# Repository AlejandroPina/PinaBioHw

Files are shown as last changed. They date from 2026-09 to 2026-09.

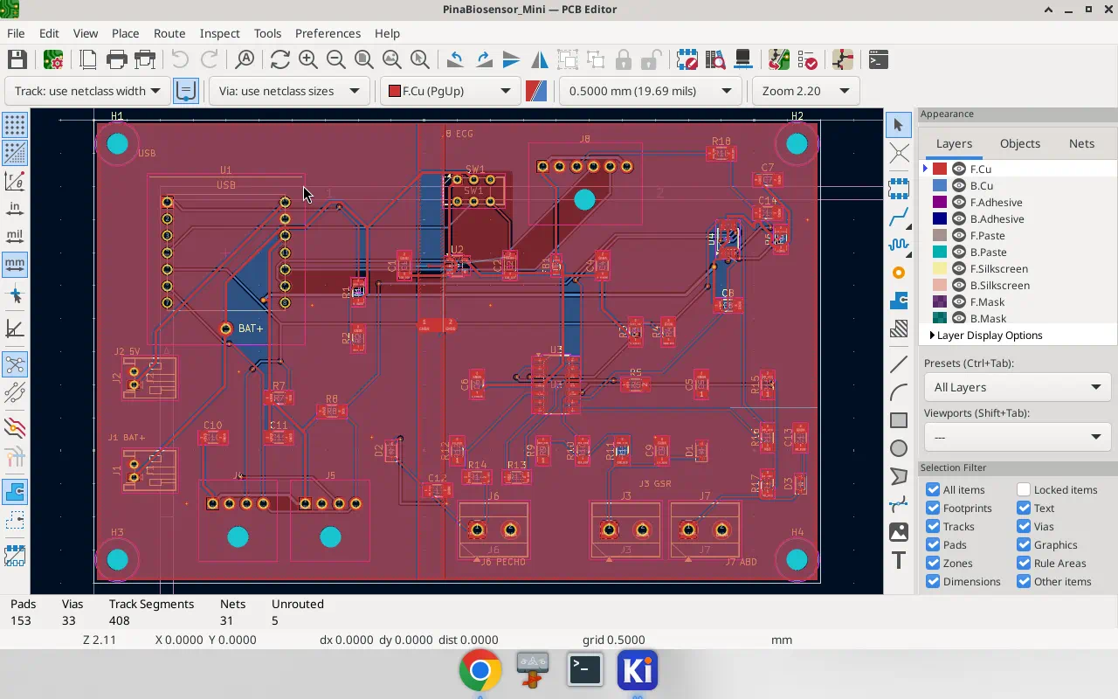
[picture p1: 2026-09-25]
exports/kicad_open.png

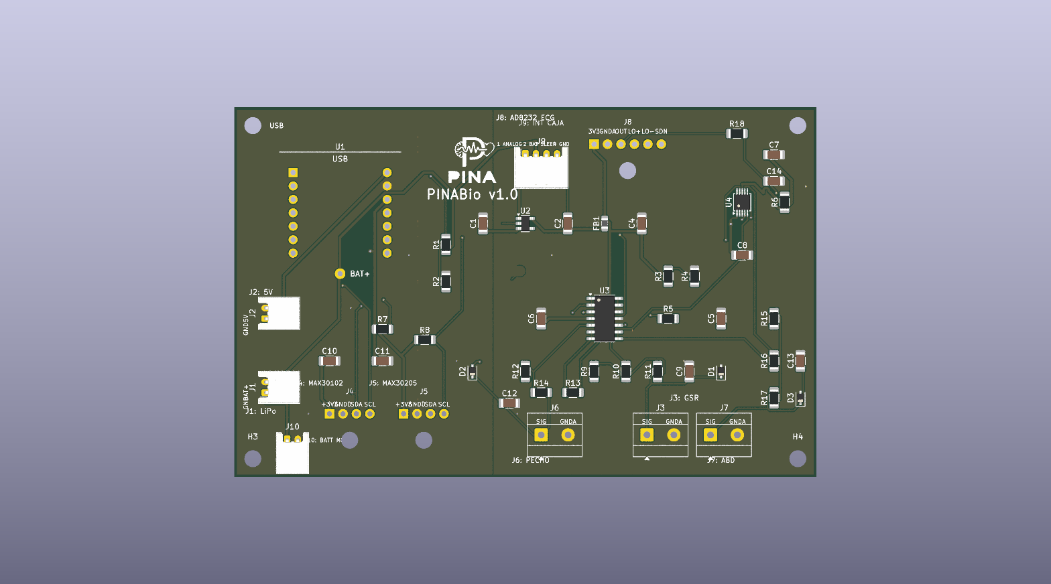
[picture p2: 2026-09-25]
exports/pcb_3d_caja.png

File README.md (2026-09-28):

[English](#) | [Español](README.es.md)

**Versión en español:** [README.es.md](README.es.md)

# PinaBio v1.0 (Paca)

The **paid JLCPCB order** is **v1.0** (`exports/PinaBio_v1_*`). A **v1.1 layout** (XIAO USB at the board edge) is ready for a **later** spin: `exports/PinaBio_v1.1_*` and `docs/10_pinabio_v1.1_rf.md`. Same circuit. Do not mix v1.1 files into the current order.

**PinaBio** is a **biofeedback** board (skin conductance, pulse, temperature, ECG, breathing). It is **not a medical device** and does not diagnose anything. The nickname **Paca** is a tribute to Alejandro’s grandmother.

Phone Bluetooth advertises as **`PinaBiosensor`**. Keep this BLE name for firmware clients.

## What the board is

One PCB, about **110 × 70 mm**, microcontroller **Seeed XIAO ESP32-S3** in a socket:

- GSR (skin)
- Pulse / HRV (MAX30102) — raw PPG for external HRV analysis
- Temperature (MAX30205)
- ECG (AD8232 module — lab toy, not a hospital ECG)
- Chest + abdomen breathing (stretch bands that change resistance)

Older notes call this same board “Completa”. KiCad files stay named `PinaBiosensor_Mini.*` on purpose (renaming breaks the project). Silk says **PINA** / **PINABio v1.0** (no “Paca” on copper — it does not fit).

Charge the XIAO from its USB-C. **With electrodes or bands on skin: Bluetooth only. Never USB from a PC and skin at the same time.**

The paid v1.0 fabrication trio is in `exports/` on `main`: `PinaBio_v1_gerbers.zip`, `PinaBio_v1_bom_jlc.csv` and `PinaBio_v1_cpl.csv`. Their committed bytes match `exports/archive_v1.0/SHA256SUMS`. See the [order guide](docs/08_jlcpcb_order.md) before a repeat order.

## Safety (read this)

This design is **not** USB-isolated. Full text: `docs/04_seguridad.md`.

1. **Never** USB to a computer while GSR, bands, or ECG electrodes are on the body.
2. Charge / flash firmware with **skin disconnected**.
3. A session with skin = **BLE only**.
4. LiPo **with a protection board** only. JST J1: pin 1 +, pin 2 ground.
5. Not for diagnosis, not for use on wounds, not a medical product.

## Order PCBs (JLCPCB)

**5** bare boards, **2** assembled (PCBA). Step-by-step: [English order guide](docs/08_jlcpcb_order.md) · [Español](docs/08_pedido_jlcpcb.md).

For a repeat order, use the three `PinaBio_v1_*` files in `exports/` on `main` and verify their hashes against `exports/archive_v1.0/SHA256SUMS`. The old `kicad-completa` branch is no longer needed. Do **not** substitute the loose `exports/gerbers/` files or the v1.1 package.

## Firmware

Board sketch (Arduino, XIAO ESP32-S3):

`firmware/PinaBiosensor_Firmware_v1_3/PinaBiosensor_Firmware_v1_3.ino`

Firmware 1.2 is kept at `firmware/PinaBiosensor_Firmware_v1_2/` for rollback.

BLE name: `PinaBiosensor`. Current protocol: `docs/firmware_v1_3_protocol.en.md` (binary byte still `0x12`, same as 1.2). Instructions: `firmware/README.md`. Changes: `firmware/CHANGELOG_v1_3.md`.

Firmware debug JSON is v4. Binary frame details are in the protocol specification.

## Open the PCB in KiCad

See `docs/03_guia_kicad.md`. Short version:

1. Install [KiCad 8](https://www.kicad.org/) **with libraries**. Do not create a new project.
2. Open `hardware/PinaBiosensor_Mini.kicad_pro`.
3. The schematic is a text map. The board you order is the PCB.

## Suggested fab (summary)

- JLCPCB / PCBWay, 2 layers, FR4 1.6 mm, green mask, HASL or ENIG.
- Factory SMT: 1206, SOT-23-5, SOIC-14, ADS1115 (VSSOP-10, very small).
- You fit: XIAO, MAX/AD8232 modules, battery, box switch on **J9**, optional meter on **J10**.

Design BOM: `bom/BOM.csv`.

## More docs

- `docs/02_arquitectura.md` — architecture
- `docs/04_seguridad.md` — safety (EN + ES)
- `docs/firmware_v1_3_protocol.en.md` — BLE UUIDs and current frames (byte `0x12`)
- `docs/firmware_v1_2_protocol.en.md` — V1.2 frames (kept for rollback)
- `docs/08_jlcpcb_order.md` — order (English)
- `docs/08_pedido_jlcpcb.md` — pedido (español)
- `docs/09_caja_interruptor_medidor.md` — box DPDT (4 wires) and J10

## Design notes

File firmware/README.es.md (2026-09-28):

# Firmware PinaBiosensor 1.3 — Paca v1.0 fabricada

[English](README.md) · [Protocolo 1.3](../docs/firmware_v1_3_protocol.es.md) · [Guía 1.3](../docs/firmware_v1_3_code_guide.es.md) · [Verificación](../docs/firmware_v1_3_verification.md) · [Cambios 1.3](CHANGELOG_v1_3.md)

**Sketch vigente:** `PinaBiosensor_Firmware_v1_3/PinaBiosensor_Firmware_v1_3.ino`

**Se conserva por si hay que volver:** `PinaBiosensor_Firmware_v1_2/` con [protocolo 1.2](../docs/firmware_v1_2_protocol.es.md) y [changelog 1.2](CHANGELOG_v1_2.md).

Mismo hardware Paca v1.0, nombre BLE `PinaBiosensor`, Wi-Fi apagado. No es dispositivo médico. Los frames binarios siguen con byte **`0x12`**.

## Compilación y carga

Arduino IDE o CLI, placa **Seeed XIAO ESP32-S3**, core Arduino-ESP32 y SparkFun MAX3010x. Carpeta y `.ino` con el mismo nombre. Electrodes fuera antes de USB.

## Uso

Los mismos comandos que 1.2. `STATUS` empieza por `fw=1.3 proto=0x12`. `STOP` pone a cero la vista previa de pulso. `START` sigue pudiendo devolver `ERR START_PPG_FIFO`.

No hay interlock por software de USB (no hay GPIO de VBUS). Cargar con power bank está bien; piel fuera mientras el cable esté puesto.

## Verificación

1.3 corrige comportamiento de 1.2. Hay que compilar y medir SPS de ECG en la XIAO tras el cambio del sondeo ADS.

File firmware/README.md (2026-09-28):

# Firmware PinaBiosensor 1.3 — fabricated Paca v1.0

[Español](README.es.md) · [Protocol 1.3](../docs/firmware_v1_3_protocol.en.md) · [Code guide 1.3](../docs/firmware_v1_3_code_guide.en.md) · [Verification](../docs/firmware_v1_3_verification.md) · [Changelog 1.3](CHANGELOG_v1_3.md)

**Current sketch:** `PinaBiosensor_Firmware_v1_3/PinaBiosensor_Firmware_v1_3.ino`

**Kept for rollback:** `PinaBiosensor_Firmware_v1_2/` with [protocol 1.2](../docs/firmware_v1_2_protocol.en.md) and [changelog 1.2](CHANGELOG_v1_2.md).

Same Paca v1.0 hardware: ADS1115 `0x49`, MAX30102 `0x57`, MAX30205 `0x48`; D4/D5 I²C, D3/GPIO4 sleep, D8/D9 leads-off, D0/A0 battery. BLE name `PinaBiosensor`. Wi-Fi off. Not a medical device. Binary frames still use version byte **`0x12`**.

## Build and upload

Arduino IDE or Arduino CLI, board **Seeed XIAO ESP32-S3**, Arduino-ESP32 core, SparkFun MAX3010x Pulse and Proximity Sensor Library. Folder name must match the `.ino`. Disconnect electrodes before USB flash.

## Operation

Same commands as 1.2 (`START`, `STOP`, `STATUS`, `USB_MODE`, rates, `SLEEP`, …). `STATUS` starts with `fw=1.3 proto=0x12`. `STOP` clears the on-MCU pulse preview. `START` still returns `ERR START_PPG_FIFO` if the MAX30102 FIFO cannot be verified.

There is no software USB-presence interlock (no VBUS GPIO). Charge with a power bank if you want; still keep skin contacts off while the cable is in.

## Verification status

1.3 is a behavioural fix on 1.2. Compile and bring-up on the XIAO are required before calling it session-ready. Measure ECG SPS after the ADS poll change.

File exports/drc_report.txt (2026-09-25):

** Drc report for PinaBiosensor_Mini.kicad_pcb **
** Created on 2026-09-12T10:42:11+0000 **

** Found 0 DRC violations **

** Found 0 unconnected pads **

** Found 0 Footprint errors **

** End of Report **

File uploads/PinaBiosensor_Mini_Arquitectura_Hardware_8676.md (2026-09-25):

# Documento de Arquitectura de Hardware: PinaBiosensor Mini

**Versión:** 1.0 (basada en PinaBiosensor 1.0 v2.0, reducida)
**Objetivo:** Especificaciones para el diseño de la PCB en KiCad de una versión simplificada del biofeedback, centrada en tres señales: **conductancia de la piel (GSR)**, **temperatura de la piel** y **pletismografía/HRV (PPG)**.

Este documento asume que llevas tiempo sin tocar electrónica, así que cada bloque incluye un breve repaso de "por qué" antes del "cómo".

---

## 0. Qué cambia respecto a la versión completa

| Bloque | Versión completa | Versión Mini |
|---|---|---|
| ECG (AD8232) | Sí | **Eliminado** |
| Respiración (bandas resistivas x2) | Sí | **Eliminado** |
| GSR | Sí (jack TRRS) | Sí, pero con **terminal de tornillo** |
| SpO2/PPG (MAX30102) | Sí (jack TRRS) | Sí, **cable soldado directo** |
| Temperatura | Analógica, vía ADS1115 (no existía en la versión completa; aquí se introduce) | **MAX30205, digital I2C**, cable soldado directo |
| MCP6004 (op-amp) | 3 canales en uso (A, B, C) | **1 canal en uso (A)**, resto sin usar (ver §3.4) |
| ADS1115 | 4 canales multiplexados | **1 canal en uso (AIN1)** |
| Conectores de sensores | AudioJack4 (TRRS 3.5mm) | Terminal de tornillo (GSR) + pads soldados con anclaje (I2C) |
| Alimentación, carga, switch ON/OFF | — | **Sin cambios** |

---

## 1. Microcontrolador

**Seeed Studio XIAO ESP32-S3**, montado igual que en la versión completa: no va soldado directamente a la placa base, sino insertado en dos tiras de conectores hembra `Conn_01x07`, para poder sacarlo y reprogramarlo o reutilizarlo en otro proyecto.

---

## 2. Sistema de Alimentación (sin cambios)

Repaso rápido de por qué esto es así, ya que es la parte más delicada del diseño:

- **V_BATT**: la batería LiPo se conecta directamente al pin `BAT` del XIAO. El propio módulo XIAO ya incluye el circuito de carga (chip cargador de Li-Po), así que no hay que diseñar nada de carga desde cero.
- **Monitor de batería**: un divisor resistivo de dos resistencias de 47kΩ (1%) reduce la tensión de la batería a la mitad, y ese punto medio va al pin `A0` (ADC interno del ESP32-S3) para poder leer el nivel de batería por software.
- **V_ANALOG (3.3V "limpios")**: la circuitería analógica (sensores) es sensible al ruido que meten los circuitos digitales (el WiFi/BLE del XIAO, por ejemplo). Por eso no se alimenta directamente de V_BATT, sino de un regulador LDO dedicado (**ADP150AUJZ-3.3**), seguido de un filtro LC (ferrita de 600Ω @ 100MHz + condensador de 10µF) que actúa como un "colador" de ruido de alta frecuencia.
- **V_REF (0.5V exactos)**: tensión de referencia necesaria para el circuito de GSR (ver §3.1). Se genera con un divisor de precisión (56kΩ y 10kΩ al 0.1%) desde V_ANALOG, y se "bufferiza" con un amplificador operacional en configuración seguidor de tensión — es decir, el op-amp copia esa tensión pero con muy baja impedancia de salida, para que no varíe cuando el circuito de GSR "tire" de corriente de ella.

**Interruptor ON/OFF (SW1)** y **carga (J_CHARGE, J_BATT)**: idénticos a la versión completa. El interruptor solo corta la alimentación del dominio analógico (V_ANALOG) y fuerza el microcontrolador a Deep Sleep (contacto a GPIO3), pero **nunca interrumpe la ruta de carga**, que va directa a los pads BAT del XIAO. Esto significa que puedes cargar la batería con el sistema "apagado" sin ningún problema — no hay que rediseñar nada aquí.

---

## 3. Sensores

### 3.1 Conductancia de la Piel (GSR) — el sensor más delicado

**Repaso del concepto:** la piel actúa como una resistencia variable que cambia con la sudoración (respuesta de conductancia, muy usada en biofeedback de estrés/relajación). Para medirla, hacemos un divisor de tensión donde una de las "resistencias" es la propia piel, y medimos el punto medio.

**Topología** (idéntica a la versión completa):

```
V_REF (0.5V) → R_FIXED (100kΩ) → Nodo_MID → Electrodos (piel) → GNDA
```

- El **Nodo_MID** se conecta a `AIN1` del ADS1115.
- **Electrodos**: par de electrodos Velcro tipo GSR/SC (los que te han recomendado), conectados a la placa mediante un **terminal de tornillo de 2 pines** (ver §4). No es necesario respetar polaridad — la piel actúa como resistencia pura, no como diodo.

**Filtros de protección** (mantener tal cual, incluso más importantes ahora sin jack blindado):

1. **C_shunt (100nF)**: en paralelo con los electrodos, entre el terminal de tornillo y GNDA. Estabiliza la lectura frente a pequeños movimientos/contactos intermitentes.
2. **R_limit (470Ω)**: en serie entre el Nodo_MID y el pin AIN1, protege la entrada del ADC.
3. **R_series (47Ω)**: en serie justo a la entrada del terminal de tornillo, protección ESD (descargas electrostáticas) — recuerda que aquí hay piel humana en contacto directo con el circuito.

**ADC**: el ADS1115 se alimenta desde V_ANALOG, con `ADDR` conectado también a V_ANALOG (fija la dirección I2C en `0x49`). Ya que solo usamos un canal, el firmware configura ganancia ×8 (rango ±0.512V) para aprovechar toda la resolución del ADC en el rango de tensión donde se mueve la señal.

### 3.2 Pletismografía / HRV — MAX30102

Sensor óptico todo-en-uno (LED + fotodiodo + ADC interno), dirección I2C `0x57`. No necesita ningún acondicionamiento analógico externo — toda la "electrónica difícil" ya está dentro del chip.

- **VCC** → V_ANALOG (alimentación limpia; mejora la relación señal/ruido de la medida óptica).
- **GND** → GNDD (es un chip digital con picos de corriente al encender los LEDs; conviene que esos picos vayan al plano digital y no contaminen GNDA).
- **SDA/SCL** → bus I2C compartido (pull-ups de 2.2kΩ a 3.3V digital, ya presentes en el bus).
- **Conexión física**: cable de 4 hilos soldado directo a 4 pads en la placa (ver §4).

### 3.3 Temperatura de la Piel — MAX30205 (recomendado sobre NTC)

Sensor digital I2C específico para temperatura corporal, dirección `0x48`.

**Por qué este y no un NTC** (repaso, ya que llevas tiempo sin ver esto): un NTC es una resistencia que cambia con la temperatura, pero para leerla necesitas (a) un divisor de tensión con otra resistencia de precisión, (b) un canal ADC libre, y (c) calcular la temperatura con una fórmula de calibración (ecuación de Steinhart-Hart) en el firmware. El MAX30205 se salta los tres pasos: es un termómetro que habla I2C y te devuelve grados directamente, con una resolución de 0.0039°C — más que suficiente para detectar las tendencias lentas típicas del biofeedback de temperatura periférica (técnica de "manos calientes").

- **VCC** → V_ANALOG
- **GND** → GNDD
- **SDA/SCL** → mismo bus I2C
- **Conexión física**: cable de 4 hilos soldado directo (comparte el mismo patrón de pads que el MAX30102, ver §4).

### 3.4 Amplificador Operacional MCP6004 — uso reducido

En la versión completa se usaban 3 de los 4 canales del MCP6004 (buffer de V_REF, y dos buffers de respiración). En la versión Mini **solo se usa el canal A** (buffer de V_REF para el GSR).

**Importante (repaso de un detalle que se olvida fácilmente):** los canales B, C y D del MCP6004 **no pueden quedar con la entrada al aire**. Un op-amp con la entrada flotante puede oscilar y meter ruido de alta frecuencia en toda la placa, incluyendo en el canal A que sí usas (todos comparten el mismo chip y la misma alimentación interna). La solución estándar y sin coste: conecta la entrada no inversora de cada canal no usado a GNDA, y realimenta la salida a la entrada inversora (configuración de seguidor de tensión con entrada a masa). Esto los deja "en reposo" de forma segura.

---

## 4. Conectores de Sensores (nuevo respecto a la versión completa)

Se elimina el conector `AudioJack4` (TRRS) para todos los sensores. En su lugar:

| Sensor | Conector | Motivo |
|---|---|---|
| GSR (electrodos Velcro) | **Terminal de tornillo, 2 pines**, paso 5.08mm | Se pone y se quita en cada uso; no requiere soldar ni crimpar, solo pelar el hilo e insertarlo |
| MAX30102 | **4 pads pasantes** (VCC, GND, SDA, SCL) + 1 **agujero de anclaje** junto a ellos | Cable soldado directo, se instala una vez; el agujero permite pasar una brida o poner pegamento caliente para evitar que el tirón del cable arranque los pads |
| MAX30205 | **4 pads pasantes** (VCC, GND, SDA, SCL) + 1 **agujero de anclaje** | Igual que el anterior |

**Recomendación práctica de montaje:** separa los pads lo suficiente (al menos 2.54mm entre centros) para poder soldar cómodamente con un soldador normal, y coloca el agujero de anclaje a unos 5mm del grupo de pads, no pegado a ellos, para que la brida no interfiera con la soldadura.

---

## 5. Planos de Masa (sin cambios de criterio, menos superficie a repartir)

- **GNDA** (masa analógica): bajo el ADS1115, el MCP6004, y el circuito de GSR (R_FIXED, C_shunt, terminal de tornillo).
- **GNDD** (masa digital): bajo el XIAO, el bus I2C, y los pads de MAX30102/MAX30205.
- **Net-Tie**: un único punto de unión entre GNDA y GNDD, situado cerca del LDO ADP150 y del XIAO, igual que en la versión completa.

Al haber menos componentes analógicos, el plano GNDA es más pequeño, pero el criterio de separación es exactamente el mismo: evitar que el ruido digital (conmutación del XIAO, BLE) se cuele en la medida de GSR, que es la más sensible de las tres señales.

---

## 6. Clases de Red (Net Classes)

Sin cambios respecto a la versión completa:

- **Alimentación** (V_BATT, 3.3V, V_ANALOG): 0.4–0.5 mm de ancho de pista.
- **Señales analógicas** (Nodo_MID del GSR, V_REF): 0.25 mm, alejadas de las pistas I2C.
- **Bus I2C** (SDA, SCL): 0.25 mm, cortas y paralelas, sobre el plano GNDD.

---

## 7. Lista de Componentes (BOM) — resumen

| Componente | Cantidad | Notas |
|---|---|---|
| Seeed XIAO ESP32-S3 | 1 | Módulo plug-in, no soldado |
| Conn_01x07 hembra | 2 | Zócalo para el XIAO |
| LDO ADP150AUJZ-3.3 | 1 | V_ANALOG |
| Ferrita 600Ω @ 100MHz | 1 | Filtro LC de V_ANALOG |
| Condensador 10µF | 1 | Filtro LC de V_ANALOG |
| Resistencias 47kΩ 1% | 2 | Divisor monitor de batería |
| Resistencias 56kΩ / 10kΩ 0.1% | 1 + 1 | Divisor V_REF |
| MCP6004 | 1 | Solo canal A en uso |
| Condensador 4.7µF | 1 | Estabilidad salida buffer V_REF |
| ADS1115 | 1 | Solo canal AIN1 en uso |
| Resistencias pull-up I2C 2.2kΩ | 2 | SDA, SCL |
| Resistencia R_FIXED 100kΩ | 1 | Divisor GSR |
| Condensador C_shunt 100nF | 1 | GSR |
| Resistencia R_limit 470Ω | 1 | GSR |
| Resistencia R_series 47Ω | 1 | GSR |
| Terminal de tornillo 2 pines, 5.08mm | 1 | Electrodos GSR |
| MAX30102 (módulo/breakout) | 1 | I2C 0x57, pads soldados |
| MAX30205 | 1 | I2C 0x48, pads soldados |
| SW1 (interruptor doble contacto) | 1 | Sin cambios vs. versión completa |
| J_CHARGE, J_BATT | 1 + 1 | Sin cambios |

---

## Siguiente documento

Como no tienes experiencia previa con KiCad, el siguiente documento (`PinaBiosensor_Mini_Guia_KiCad_Principiantes.md`) te lleva paso a paso desde instalar el programa hasta generar los ficheros para fabricar esta placa concreta.

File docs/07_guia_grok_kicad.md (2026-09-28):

# Encargo para Grok — generar KiCad de PinaBio v1.0

Documento para pegar o adjuntar a **Grok** (Cursor u otro agente con acceso al repo y a KiCad).  
Autor del proyecto: Alejandro. **No es un dispositivo médico.**

---

## 0. ¿Es posible?

**Sí, con matices.**

| Encargo | Realista |
|---|---|
| Esquemático **de verdad** (símbolos + hilos + etiquetas globales) | Sí, si Grok usa KiCad 8 y las librerías de este repo |
| PCB colocada, planos GNDA/GNDD, net-tie | Sí |
| Pistas **sin errores DRC** (listo para JLCPCB) | **A veces no a la primera.** Debe **iterar**: DRC → corregir → DRC hasta 0 errores. No entregar Manhattan sucio y decir “listo” |
| Firmware | El sketch V1.2 está en `firmware/`; esta guía se centra en KiCad, Gerbers y BOM |

Si no tienes KiCad instalado, **no inventes un `.kicad_pcb` a mano**. Di que falta KiCad. No sustituyas la placa por un dibujo ASCII.

---

## 1. Qué eres y qué no

Eres el **layoutista**. El circuito **ya está decidido**. No “mejoras” la arquitectura (no cambies pines de sleep, no pongas cargador extra, no alimentes I2C desde V_ANALOG, no uses GPIO3 para el interruptor).

**Olvida la Mini como producto.** El diseño se llama **PinaBio v1.0**. Los archivos KiCad siguen `PinaBiosensor_Mini.*` (**no los renombres**). El ZIP original del pedido está restaurado como `exports/PinaBio_v1_gerbers.zip` en `main`; su hash coincide con `exports/archive_v1.0/SHA256SUMS`. No lo sustituyas por los gerbers sueltos de `exports/gerbers/`.

---

## 2. Archivos que debes leer primero (en este orden)

1. Este archivo: `docs/07_guia_grok_kicad.md`
2. `docs/02_arquitectura.md`
3. `docs/04_seguridad.md`
4. `scripts/generate_kicad.py` — **fuente eléctrica** (nets y pines)
5. `hardware/sym-lib/Pina.kicad_sym`
6. `hardware/footprints.pretty/` (XIAO zócalo, cables 4P y 6P)
7. `firmware/PinaBiosensor_Firmware_v1_3/PinaBiosensor_Firmware_v1_3.ino` — firmware vigente y pines de la PCB v1.0 (no contradecir). V1.2 se conserva para rollback.

No uses `uploads/PinaBiosensor_Mini_Guia_KiCad_Principiantes_*.md` (está mal: GPIO3, etiquetas jerárquicas, sensores a V_ANALOG).

---

## 3. Circuito congelado (no negociar)

### MCU
Seeed **XIAO ESP32-S3** en zócalo 2×7, paso 2,54 mm, filas 17,78 mm. USB hacia el **borde** de la placa.  
Pad **BAT+** no está en los 14 pines: huella extra + **hilo** al pad BAT del módulo.

| Función | Pin XIAO | GPIO |
|---|---|---|
| Divisor batería | D0 / A0 | 1 |
| Sleep SW1 | **D3** | **4** (nunca D2/GPIO3) |
| SDA | D4 | 5 |
| SCL | D5 | 6 |
| ECG LO+ | D8 | 7 |
| ECG LO− | D9 | 8 |

Carga LiPo: **solo el USB-C del XIAO**. SW1 **no** corta BAT.  
SW1 DPDT: polo A = V_BATT → VIN del LDO analógico. Polo B OFF = D3 a GND.

### Alimentación analógica
ADP150-3.3. Datasheet: ≥1 µF en VIN y VOUT. Pin 4 del ADP150 es **NC**, no BYP: **no pongas 1 nF a un pin BYP que no existe** si el símbolo está mal; corrige el símbolo a NC si hace falta. Ferrita + 10 µF **después** del LDO = `V_ANALOG`.

### Masas
`GNDA` (GSR, bandas, MCP6004, ADS pin GND, AD8232 GND) y `GNDD` (XIAO, LDO GND, I2C). **Un** net-tie `NT1` junto al LDO.

### I2C
Pull-ups 2,2 kΩ a **`+3V3` del XIAO**. ADS1115, MAX30102, MAX30205 alimentados de **`+3V3`**, no de V_ANALOG.  
ADS ADDR a +3V3 → **0x49**.

### V_REF y GSR
56k/10k 0,1 % desde V_ANALOG → ~0,50 V. MCP6004 canal **A** seguidor. **Riso 47 Ω** entre salida y 4,7 µF (realimentación **antes** de Riso).  
GSR: V_REF → 100 kΩ → MID → piel → GNDA. Serie 1 kΩ + TVS 5 V + 100 nF en electrodo. 470 Ω a AIN1. Ganancia firmware ×8.

### Bandas (goma resistiva)
Igual idea, 47 kΩ desde V_REF. Canal **B** pecho (J6), **C** abdomen (J7). Canal **D** seguidor a GNDA. TVS + 100 nF + 1 kΩ como GSR.

### ECG
Módulo **AD8232** fuera de la PCB. J8 6 pads: 3V3(V_ANALOG) / GNDA / OUT / LO+ / LO− / SDN.  
SDN a **V_ANALOG** (activo en alto mientras el analógico está ON). OUT → 1 kΩ → AIN0, 100 nF a GNDA. Ganancia ×1.

### Conectores
| Ref | Qué |
|---|---|
| J1 | LiPo JST-PH |
| J2 | 5 V opcional (mismo 5V XIAO) |
| J3 | GSR tornillo 2P |
| J4 | MAX30102 4 pads + agujero brida |
| J5 | MAX30205 4 pads + agujero |
| J6 | Banda pecho tornillo 2P |
| J7 | Banda abdomen tornillo 2P |
| J8 | AD8232 6 pads + agujero |

---

## 4. Entregables (obligatorios)

Al terminar, deben existir y **abrir en KiCad 8 sin errores de librería**:

- `hardware/PinaBiosensor_Mini.kicad_pro` (o `PinaBiosensor.kicad_pro` si renombras todo)
- `.kicad_sch` — **símbolos reales**, no un muro de texto
- `.kicad_pcb` — contorno, piezas, pistas, vias, zonas GNDA/GNDD rellenas
- `bom/BOM.csv` actualizado si cambian valores
- `exports/gerbers/` regenerados **después** de DRC = 0 errores
- Captura o log: **DRC 0 errors** (avisos courtyard se discuten, no se ignoran a ciegas)

No hace falta firmware nuevo.

---

## 5. Paso a paso (sigue este orden)

### Paso A — Entorno
1. KiCad **8** (o 7) **con librerías oficiales**.
2. Abre el proyecto desde el `.kicad_pro`, no el PCB suelto.
3. Comprueba `fp-lib-table` / `sym-lib-table`: librería **Pina** → `footprints.pretty` y `sym-lib/Pina.kicad_sym`.

### Paso B — Esquemático de verdad
1. Puedes partir de `scripts/generate_kicad.py` (SKiDL) para no perder nets, **pero** el `.kicad_sch` final debe ser dibujado o exportado con símbolos visibles.
2. Etiquetas **globales** (`V_ANALOG`, `+3V3`, `GNDA`, `GNDD`, `SDA`, `SCL`…). **Prohibido** “etiqueta jerárquica global”.
3. Power flags / símbolos de alimentación en cada red de power.
4. ERC: 0 errores. Warnings de “insufficient drive” en power a veces se limpian con PWR_FLAG; no dejes pines de chip al aire (AIN usados; MCP D terminado).
5. Anota en el cajetín: “PinaBio v1.0 — no sanitario — USB nunca con piel”.

### Paso C — Asociar huellas
Todos los ref del netlist tienen footprint. ADS1115 = VSSOP-10 / TSSOP-10 3×3 P0.5 **de máquina**. Resistencias/condensadores **1206**.

### Paso D — PCB mecánica
1. Contorno ~**110 × 70 mm** (2 capas, 1,6 mm). 4 taladros M3 en esquinas.
2. Colocación:
   - XIAO USB al borde superior.
   - Analógico (MCP, GSR, bandas, ADS, AD8232 pads) **a un lado**; digital/XIAO al otro; NT1 en la frontera.
   - Tres bornes en un borde, fáciles de cablear.
   - J8 lejos del borde USB si puedes (menos lío de cables).
3. Clases: alimentación ≥ 0,45 mm; resto ≥ 0,25 mm; holgura ≥ 0,15 mm (JLCPCB 2 capas estándar).

### Paso E — Planos y pistas
1. Zona **GNDD** (F+B) zona izquierda/centro; **GNDA** derecha; solape solo en NT1.
2. Rellena zonas (`B`).
3. Enruta (a mano o Freerouting). **Prohibido** dejar el router Manhattan cruzado como entrega final.
4. `Inspeccionar → DRC`. Corrige **todos** los errores: clearance, unconnected, short, edge clearance, hole.
5. Repite E4 hasta **0 errors**. Si en 3 ciclos no bajas de ~10 errores, cambia estrategia (menos autorruta, más a mano en I2C y GSR).

### Paso F — Revisión visual (obligatoria)
Visor 3D:

- USB fuera, no contra el centro.
- Silkscreen: J1 BAT+/GND, J3 GSR, J6 PECHO, J7 ABD, J8 ECG, pad BAT+.
- Nada de courtyard aplastado sin comentario.

### Paso G — Fábrica
Gerbers + drill. ZIP. No subir Gerbers **viejos** de `exports/` de la Mini.

Pedido sugerido (coméntalo, no lo pagues tú): 5 PCB, 2 ensambladas SMT (incluido ADS1115), 3 vírgenes. THT lo suelda Alejandro.

---

## 6. Prohibiciones explícitas

- USB isolator en PinaBio v1.0 (D+/D− no salen al zócalo).
- Cortar la carga con SW1.
- Sleep en GPIO3.
- MAX30102 a V_ANALOG.
- 4,7 µF colgado en la salida del MCP **sin** Riso.
- Jacks TRRS (ya descartados).
- SHT41 (usamos MAX30205).
- Inventar SpO2 o HRV en la placa.
- Crear un proyecto KiCad **vacío** ignorando este repo.

---

## 7. Cómo sabe Alejandro que has acabado

1. Abre el `.kicad_pro` → esquemático se **ve** (chips, no solo párrafos).
2. PCB visor 3D: 3 bornes + conector 6 pads ECG.
3. DRC: **0 errores**.
4. Mensaje corto en castellano sencillo: qué tocaste y qué Gerber usar.

Si el DRC no llega a cero, **no mientas**. Lista los errores que quedan y por qué.

---

## 8. Prompt corto para pegar a Grok

```
Lee docs/07_guia_grok_kicad.md y obedece. Eres layoutista de PinaBio v1.0.
Genera esquemático real + PCB DRC limpio + Gerbers nuevos.
No cambies la arquitectura ni el firmware. No uses la guía de principiantes de uploads/.
Itera DRC hasta 0 errores. Al final explica en castellano simple qué entregaste.
```

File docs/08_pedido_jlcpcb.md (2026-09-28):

[English](08_jlcpcb_order.md) | [Español](#)

# Guía de pedido JLCPCB — PinaBio v1.0 (Paca)

> **Archivo verificado restaurado en `main` (28-09-2026).** Los tres ficheros `exports/PinaBio_v1_*`, incluido el ZIP original de gerbers, coinciden en SHA-256 con `exports/archive_v1.0/SHA256SUMS`. Comprueba esos hashes antes de repetir el pedido; no los sustituyas por `exports/gerbers/` ni por v1.1.

Para: **Alejandro**. No hace falta KiCad. No abras ni edites los archivos de fabricación.

Producto: **PinaBio v1.0** (apodo **Paca**, homenaje a la abuela de Alejandro). En el teléfono, el Bluetooth sigue llamándose **`PinaBiosensor`** (no lo cambies).

Hay una placa **v1.1** (USB del XIAO al borde) para **un pedido más adelante**. Para **este** pedido usa **`PinaBio_v1_*`**, no `PinaBio_v1.1_*`. Ver `docs/10_pinabio_v1.1_rf.md`.

La antigua rama `kicad-completa` no existe en el remoto GitHub actual. Los archivos verificados del pedido están ahora directamente en `exports/` de `main`.

---

## 0. Qué tendrás al final

Un solo pedido. La fábrica fabrica **5 placas** y suelda componentes en **2** de ellas.

- **2 placas ensambladas** (con resistencias, condensadores, chips y conectores soldados por la fábrica).
- **3 placas vírgenes** (solo el circuito impreso verde, sin piezas). Sirven de recambio o para practicar.

Eso **no** incluye el módulo XIAO, los sensores MAX/AD8232, la batería, las bandas ni el interruptor de la caja. Esos los compras tú (apartado 7).

Esto **no** es un aparato médico. No diagnostica. Con electrodos o bandas en la piel: **solo Bluetooth**. El USB del PC **nunca** a la vez que la piel.

---

## 1. Dónde están los 3 archivos (Windows)

Necesitas **exactamente 3 archivos**. Nombres actuales (septiembre 2026):

| Para qué | Nombre exacto | Dónde (Windows) |
|---|---|---|
| Cobre / taladros / seda (la placa) | `PinaBio_v1_gerbers.zip` | `exports\PinaBio_v1_gerbers.zip` |
| Lista de piezas para la fábrica | `PinaBio_v1_bom_jlc.csv` | `exports\PinaBio_v1_bom_jlc.csv` |
| Dónde va cada pieza | `PinaBio_v1_cpl.csv` | `exports\PinaBio_v1_cpl.csv` |

Hay **copias idénticas** con el nombre antiguo «Completa» (es **la misma placa**):

- `exports\PinaBiosensor_Completa_gerbers.zip`
- `exports\PinaBiosensor_Completa_bom_jlc.csv`
- `exports\PinaBiosensor_Completa_cpl.csv`

Usa preferiblemente los de **PinaBio_v1_***. Si ya empezaste un presupuesto con los Completa, no mezcles: sigue con el mismo trío.

**No uses** la carpeta `exports\gerbers\` con archivos `PinaBiosensor_Mini-...`. Eso es **otra placa** (Mini), no PinaBio v1.0.

### Aviso importante: carpeta / rama equivocada

Los tres archivos exactos del pedido v1.0 están ahora en `exports/` de `main`. Sus hashes coinciden con `exports/archive_v1.0/SHA256SUMS`.

La rama **`kicad-completa`** ya no está disponible, pero el paquete exacto del pedido `SMT026091261919` está restaurado en `main`. Comprueba los hashes antes de continuar.

Dentro del ZIP verificado, los archivos Gerber conservan el prefijo histórico `PinaBiosensor_Mini-`. Identifica el paquete por el **hash del ZIP exterior**, no por esos nombres internos; los archivos sueltos de `exports/gerbers/` no se han verificado como el ZIP del pedido pagado.

### Si tienes el proyecto abierto en el PC

1. En el Explorador de Windows (o en el árbol de archivos de Cursor, a la izquierda), entra en la carpeta del proyecto.
2. Abre **`exports`**.
3. Copia estos tres a Escritorio o Descargas, para tenerlos a mano:
   - `PinaBio_v1_gerbers.zip`
   - `PinaBio_v1_bom_jlc.csv`
   - `PinaBio_v1_cpl.csv`

### Si usas GitHub en el navegador

Abre la rama `main`, entra en `exports/` y descarga los tres archivos `PinaBio_v1_*` de la tabla. No descargues `exports/gerbers/`. Compara los SHA-256 con `exports/archive_v1.0/SHA256SUMS` antes de subirlos a JLCPCB.

### Lo que no debes hacer

- **No abras KiCad.** No hace falta.
- **No descomprimas** `PinaBio_v1_gerbers.zip` para “arreglar” nada. A JLCPCB se sube **el ZIP entero**.
- **No edites** los CSV en Excel si te pide “convertir a números” o cambia comas. Si los abres, **no guardes**. Mejor copiarlos tal cual.

---

## 2. Registrarse en JLCPCB

1. Abre **https://jlcpcb.com** en el navegador (Chrome o Edge).
2. Arriba a la derecha pulsa **Sign up** / **Register** (Registrarse).
3. Crea cuenta con correo. Confirma el correo si te lo piden.
4. Vuelve a **https://jlcpcb.com** e inicia sesión (**Log in**).

Idioma: arriba suele haber un selector. Puedes dejarlo en inglés; abajo se indica el texto del botón.

---

## 3. Subir gerbers y revisar el visor

1. En la portada, pulsa **Quote now** (a veces **Instant Quote**). Te lleva a la página de pedido.
2. En la zona grande de subir archivos, pulsa o arrastra **`PinaBio_v1_gerbers.zip`**.
3. Espera a que termine de leer el ZIP (unos segundos). Sale un visor de la placa.

**Lista de comprobación en el visor (antes de seguir):**

- Tamaño aproximado **110 × 70 mm** (11 cm × 7 cm). Si pone 50×30 o similar, **has subido la Mini**: cancela y usa el `PinaBio_v1_gerbers.zip` verificado de `main`.
- En la seda (texto blanco) debe verse **J9** (interruptor de caja, 4 pines) y **J10** (medidor de batería, 2 pines).
- **No debe haber SW1** (no hay interruptor deslizante en la placa). El interruptor va en la **caja**, cableado a J9.
- Forma rectangular, 4 agujeros de tornillo en las esquinas.
- Texto **PINA** / **PINABio v1.0** (no pone «Paca» en la placa: no cabe).

Si el visor se ve al revés o raro, no edites el ZIP. Revisa que subiste el archivo correcto. Si 110×70 y J9/J10 están, sigue.

Pulsa **Next** / **Confirm** cuando el visor esté bien.

---

## 4. Opciones de la placa (PCB)

Deja lo que JLCPCB detecte si coincide con esto. Si no, cámbialo a mano:

| Campo (inglés) | Pon esto |
|---|---|
| **PCB Qty** (cantidad) | **5** |
| Layers (capas) | **2** |
| PCB Thickness | **1.6 mm** |
| PCB Color | **Green** (verde) |
| Surface Finish | **HASL** (estaño; vale **LeadFree HASL**). ENIG (oro) es más caro y no hace falta. |
| Copper Weight | **1 oz** (si sale) |
| Remove Mark / Order Number | puedes dejar que pongan el número de pedido en la placa (no molesta) |

No actives panel (varias placas unidas) ni agujeros chapados raros. Placa **suelta**, cantidad **5**.

**No pagues todavía.** El ensamblaje se elige en la misma página, más abajo.

---

## 5. Ensamblaje (PCBA): sí, 2 placas

1. Baja hasta **PCB Assembly**.
2. Activa el interruptor (**ON** / Yes).
3. **PCBA Qty** / Assembly Qty: pon **2** (solo 2 de las 5 se sueldan).
4. Lado: **Top side** (todo va arriba).
5. Empieza por **Economic**. Si la web **bloquea** conectores de agujero (THT: JST, bornes, zócalo) o dice que Economic no admite esos pines, cambia a **Standard** y sigue.
6. Pulsa **Confirm** / **Next**.

Tooling holes / confirmación de taladros: acepta lo que recomiende la fábrica si el visor de la placa sigue viéndose 110×70.

Si un ingeniero (p. ej. Lulu) dice que el Gerber mide **110×80** y el pedido **110×70**: responde que la **placa acabada es 110×70 mm**. Los **80 mm** son el **panel** con rieles de ~5 mm a cada lado (5+70+5) y las líneas V-CUT a 5 mm y 75 mm. **No** pidas que fabriquen una placa de 80 mm de alto.

---

## 5b. Dónde ver el diseño que van a fabricar

No está en Cursor ni en el correo de Lulu. Está en tu cuenta:

1. Entra en **https://jlcpcb.com** e inicia sesión.
2. Arriba a la derecha, tu cuenta → **Order History** (historial). Directo: **https://jlcpcb.com/user-center/orders**
3. Abre el pedido **SMT026091261919**.

Ahí verás, según el momento:

- **View PCB** / visor Gerber / **Order details** — la placa (cobre y seda). Debe medir **110 × 70**, texto **PINABio v1.0**, **J9** y **J10**, **sin SW1**.
- **Confirm production file** / **Download production file** — el archivo **después** de que el ingeniero lo prepare. Las fotos pequeñas de esa página **no bastan** (lo dice JLCPCB). Descarga el ZIP, descomprímelo y mira la carpeta **`ok`** (no `yg`: eso es lo que subiste tú). El recorte de placa es la capa **`ko`**: **110 × 70**, no 80.
- Piezas soldadas: en el mismo pedido, visor **SMT** / **Part Placement** / ensamblaje. Revisa **U2 U3 U4** contra el triángulo de seda.

Si el estado ya dice **confirmed production file** / revisado, el diseño final es ese visor + la carpeta **`ok`**. Si aún sale un botón **Yes, please proceed to production**, no lo pulses hasta ver **110 × 70** y los chips bien.

El dibujo rojo **V-CUT 80 mm** del correo es el **panel** (rieles), no la Paca.

---

## 6. Subir BOM + CPL, emparejar, DNP, polaridad

1. En **BOM file** sube `PinaBio_v1_bom_jlc.csv`.
2. En **CPL** / **CPL file** / Pick and Place sube `PinaBio_v1_cpl.csv`.
3. Pulsa **Process BOM&CPL** (o **Next** si ya procesa solo).

### Emparejado

La web rellena códigos de almacén (números tipo C1848). Revisa que casi todas las líneas tengan pieza.

Dos líneas del BOM **van en blanco a propósito** (las emparejas a mano o las marcas para no soldar si no hay pieza clara):

- **U1** — zócalo del XIAO (no el módulo). Busca 2 tiras hembra 1×7, paso 2,54 mm. Candidato de ejemplo: **C2932672** (comprueba en la ficha que es hembra 2,54 mm). Si no estás seguro, marca U1 como **no soldar** y lo sueldas tú en casa.
- **J3, J6, J7** — bornes de tornillo 2 pines, paso **5,08 mm**. Candidato: **C475082** (KF128R-5.08-2P). **Compara la foto** con el hueco de la placa. Si el cuerpo no encaja, **no sueldes en fábrica**; cómpralos aparte.

Si una línea sale en rojo (sin stock): pulsa **Search**, elige otra pieza **igual de valor y tamaño 1206** (o el encapsulado que ponga), o marca **Do not place** / no soldar esa referencia y la compras tú.

### Qué SÍ debe soldar la fábrica

Resistencias, condensadores, ferrita FB1, diodos D1 D2 D3, chips **U2 U3 U4**, conectores **J1 J2 J9 J10**, y si el servicio lo permite: zócalo **U1** y bornes **J3 J6 J7**.

### Qué NO debe soldar (DNP)

Marca **Do not place** / no ensamblar si la web los propone:

- Módulo **XIAO** (solo el zócalo, nunca el cerebro soldado a pelo si quieres poder cambiarlo).
- Módulos **MAX30102**, **MAX30205**, **AD8232**.
- Pads **J4, J5, J8** (solo cobre; no hay conector de fábrica).
- **SW1** (no existe en esta placa).
- Agujeros **H1–H4** y el puente de cobre **NT1** (no son piezas).

### Polaridad (visor de componentes)

Antes de pagar, abre el visor de piezas montadas. Mira sobre todo:

- **U2** (regulación 3,3 V, 5 patas): el triángulo de seda es pad 1 (lado de 3 patas). En el CPL, U2 va a **180°** (el PCB en KiCad sigue a 0°): misma corrección LCSC que U3; el morado debe coincidir con el triángulo, no con el lado de 2 patas.
- **U3** (chip largo 14 patas): muesca o pata 1 al mismo lado que el dibujo. En el CPL, U3 ya va a **180°** (el PCB en KiCad sigue a 0°): el pin1 del modelo LCSC es opuesto al triángulo de seda; en Part Placement el morado debe coincidir con el triángulo. **No vuelvas U3 a 0°.**
- **U4** (chip pequeño 10 patas): igual, pata 1. **No gires U4.**
- **D1 D2 D3**: orientación del diodo según la seda.
- Conectores JST: el enganche del plástico hacia el borde, como en el dibujo.

Si una pieza está girada 180°, **no pagues**: en la tabla de CPL suele haber un ángulo; dímelo y se corrige el archivo. No gires “a ojo” en Excel.

Varias resistencias 1206 son **Extended** (un recargo de carga de carrete). Es normal. U2, U3 y U4 también son Extended.

Pulsa **Next** hasta el resumen de precio.

---

## 7. Piezas que compras tú (no van en este pedido de fábrica)

Para **cada** placa que quieras usar de verdad (empiezas con las 2 ensambladas):

| Qué | Notas |
|-----|---|
| Seeed **XIAO ESP32-S3** (el módulo) | Se clava en el zócalo. Comprueba que es S3, no RP2040. |
| Zócalo 2× hembra 1×7 2,54 mm | Solo si la fábrica **no** soldó U1. |
| Bornes 5,08 mm 2P | Solo si J3/J6/J7 no salieron de fábrica. |
| Módulo **MAX30102** | Pulso; cables a pads J4. |
| Módulo **MAX30205** | Temperatura; pads J5. |
| Módulo **AD8232** | ECG de laboratorio; pads J8. **No** es un electrocardiógrafo de hospital. |
| Batería **LiPo 1S** **con placa de protección** | Conector JST hacia J1. Polaridad: pin 1 +, pin 2 masa. |
| Interruptor **DPDT de panel** + 4 hilos | A **J9**. No hay SW1 en la placa. |
| Medidor de batería (opcional) | Enchufe en **J10**. |
| Bandas de goma resistivas pecho y abdomen | A bornes J6 y J7. |
| Electrodos GSR | A borne J3. |
| Electrodos del AD8232 | Al módulo ECG, no a la placa grande. |
| Tornillos M3 + caja | Los 4 agujeros de esquina. |

El Bluetooth en el móvil se llama **PinaBiosensor**. En la placa pone PinaBio v1.0.

---

## 8. Pagar, esperar, y el primer encendido

1. Revisa el carrito: **5** placas, **2** ensambladas, color verde, 1,6 mm.
2. Elige envío (el barato tarda más; el rápido cuesta más).
3. Dirección de España / la tuya. Paga (tarjeta).
4. Espera el correo de producción. Si la fábrica escribe por un conector o un chip sin stock, no improvises: responde o pregunta antes de aceptar un recambio raro.
5. Al llegar: **2** con piezas y **3** desnudas.

### Primer encendido (seguridad)

1. **Nadie** con electrodos, bandas ni ECG puestos.
2. **USB del PC desconectado** hasta que hayas mirado la placa en seco. Luego puedes programar el XIAO por USB **sin piel**.
3. Si el XIAO no viene puesto: apaga todo, clávalo en el zócalo **en el sentido de la seda** (USB hacia el borde que indica el dibujo).
4. **Sin** batería y **sin** sensores: mira que no hay estaño uniendo pistas, ni chips torcidos.
5. Enchufa **solo USB** al XIAO, unos segundos: no debe oler a quemado ni calentarse un chip al instante. Si huele mal: USB fuera, no tires la placa a la basura normal (batería aparte, punto limpio).
6. El interruptor de caja se cablea a **J9** (4 hilos). Hasta entonces la parte analógica puede no encenderse como en el diseño final.
7. Batería **solo** con protección, en **J1**, polaridad correcta. No USB y piel a la vez **nunca**.
8. Sesión con piel: **solo Bluetooth**, USB del ordenador **fuera**.

Este pedido solo fabrica el hardware de **PinaBio v1.0**. El firmware vigente está documentado aparte en `firmware/`.

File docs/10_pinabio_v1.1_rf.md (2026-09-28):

# PinaBio v1.1 — giro de layout RF (no es el pedido actual)

**ES:** Esto es el **siguiente** giro de placa. El pedido JLCPCB que ya está en marcha (**SMT026091261919**) sigue siendo **v1.0**. No uses estos Gerbers v1.1 para ese pedido. No hace falta cancelar v1.0: v1.0 sirve para probar el circuito; v1.1 es para BLE/Wi‑Fi cuando quieras otra tirada.

**EN:** This is the **next** PCB spin. The paid JLCPCB order stays **v1.0**. Do not upload `PinaBio_v1.1_*` to that order.

Apodo **Paca** igual. Bluetooth del teléfono: **`PinaBiosensor`**. Circuito eléctrico **igual** (mismas redes, mismas piezas, mismos conectores). Solo cambia el **dibujo de cobre**: el zócalo XIAO (U1) se acerca al borde superior para enchufar el USB-C.

## Qué se movió

- Placa sigue **110 × 70 mm**, 2 capas.
- **U1** (zócalo Seeed XIAO ESP32-S3) centro en **(20.00 mm, 9.22 mm)**, rotación 0°. USB hacia el borde superior (Y = 0).
- El USB-C del módulo queda en el borde. Keepout KiCad `ANT_KEEPOUT` bajo ese extremo: **12.4–27.6 mm × 0.40–6.40 mm**, F.Cu y B.Cu (sin plano, sin pistas, sin vias). Eso evita cobre bajo el metal del USB, no es la antena de radio.
- El XIAO ESP32-S3 **no** lleva antena cerámica en el USB. El Bluetooth usa el conector **U.FL** (en el módulo, hacia `BAT+`) y el **cable-antena de la bolsa**. Hay que enchufarlo y sacar el cable de la caja de plástico. Sirve igual en v1.0 y en v1.1. No recortes la placa v1.0.
- Conectores J1, J2, J10, J9, J3, J6, J7, J8, J4, J5 **no se quitaron**. SW1 **no existe**.
- Seda: **PINABio v1.1** (sigue sin “Paca” en cobre).

## Archivos de fábrica v1.1 (próxima tirada)

- `exports/PinaBio_v1.1_gerbers.zip`
- `exports/PinaBio_v1.1_bom_jlc.csv`
- `exports/PinaBio_v1.1_cpl.csv`

## Archivos del pedido v1.0 (restaurados en `main`; comprobar SHA-256)

- `exports/PinaBio_v1_gerbers.zip`
- `exports/PinaBio_v1_bom_jlc.csv`
- `exports/PinaBio_v1_cpl.csv`
- Copia: `hardware/archive/PinaBio_v1.0/` y `exports/archive_v1.0/`

## DRC

v1.1: **0 errores / 0 unconnected** (`exports/drc_v1.1.json`).

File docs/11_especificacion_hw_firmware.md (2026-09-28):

# PinaBio v1.0 (Paca) — especificación de hardware y firmware

**Documento histórico de revisión externa (p. ej. Claude).** Describe la placa **tal como se pidió a JLCPCB** (pedido `SMT026091261919`) y analiza el firmware V1.2. El firmware vigente es [V1.3](../firmware/PinaBiosensor_Firmware_v1_3/PinaBiosensor_Firmware_v1_3.ino), con su [protocolo](firmware_v1_3_protocol.es.md) y [guía de cambios](firmware_v1_3_code_guide.es.md). No es un manual de usuario.

| Campo | Valor |
|---|---|
| Producto | PinaBio v1.0 (apodo **Paca**) |
| Nombre BLE (no cambiar) | `PinaBiosensor` |
| Ficheros KiCad | `hardware/PinaBiosensor_Mini.*` (el nombre Mini es histórico) |
| Congelado de pedido | `hardware/archive/PinaBio_v1.0/` y `exports/PinaBio_v1_*` |
| Firmware analizado aquí | V1.2 (conservado para rollback). Vigente: `firmware/PinaBiosensor_Firmware_v1_3/PinaBiosensor_Firmware_v1_3.ino` |
| Pedido fábrica | 5 PCB + 2 PCBA, verde, 1,6 mm, 2 capas, HASL, vias tented |
| Clasificación | Prototipo de **biofeedback / laboratorio personal**. **No es dispositivo médico.** No diagnostica. No cumple IEC 60601. |

**Supuestos de esta revisión histórica (no se preguntó al usuario):** idioma español; base = **v1.0 soldada**, no el layout RF v1.1; firmware analizado = V1.2; BOM “pedido real” = lo que JLCPCB emparejó en DFM (puede diferir 0,1 % vs 1 % en R3/R4 respecto al CSV del repo).

---

## 1. Qué hace y qué no hace

La placa lee:

1. Conductancia de piel (GSR) en un borne de 2 pines.
2. Pulso óptico (PPG) en un MAX30102 externo (pads I2C).
3. Temperatura cutánea aproximada en un MAX30205 externo.
4. ECG de juguete vía módulo AD8232 externo (pads de 6 hilos).
5. Dos bandas elásticas resistivas (tórax y abdomen).
6. Tensión de una LiPo 1S (el % lo calcula el teléfono).

El firmware **no** calcula HRV (RMSSD, SDNN, LF/HF). Detecta intervalos RR preliminares y envía PPG RAW para análisis posterior por un cliente externo.

**Sesión con piel:** solo Bluetooth. **Nunca** USB a un PC (masa de red / cargador) con electrodos, bandas o ECG puestos. Programar y cargar con la piel fuera.

---

## 2. Mecánica y stackup

| | |
|--|--|
| Contorno acabado | **110 × 70 mm** (no 80 mm) |
| Espesor | 1,6 mm, FR-4, 2 capas, 1 oz |
| Color / seda | Verde / blanca |
| Taladros de caja | H1–H4, M3, Ø 3,2 mm, centros (3,5; 3,5), (106,5; 3,5), (3,5; 66,5), (106,5; 66,5) mm |
| Panel JLCPCB | 110 × 80 mm = riel 5 mm + placa 70 mm + riel 5 mm; V-CUT a 5 mm y 75 mm. El ZIP `ok/ko` del ingeniero lo confirma. |

**Layout RF de esta v1.0 (defecto conocido):** zócalo U1 centrado en **(20, 20) mm**, USB hacia Y=0 pero **no** en el borde. Hay plano `GNDD` en F.Cu y B.Cu bajo el módulo. El ESP32-S3 de Seeed usa conector **U.FL** y cable-antena (no cerámica en el USB). Mitigación de uso: enchufar el cable de la bolsa y sacarlo de una caja de **plástico**, sin metal ni LiPo bajo el XIAO.

Existe un giro de cobre **v1.1** (U1 en Y=9,22 mm, USB al borde, keepout bajo el USB). **No** es este pedido. Ese keepout **tampoco** es la antena U.FL (queda hacia `BAT+`). Ver §16.

---

## 3. Árbol de alimentación

```
LiPo 1S + protección ──J1── V_BATT ──hilo── pad BAT+ del XIAO (U1 pad 15)
                         │
                         ├── J10 (medidor, paralelo a J1)
                         │
                         └── J9 pin2 ──[DPDT polo A, ON]── J9 pin1 LDO_VIN
                                                          │
USB-C del XIAO ── cargador interno del módulo ── (no cortar con el DPDT)
                                                          │
                                                    U2 ADP150AUJZ-3.3
                                                    VIN=EN=LDO_VIN
                                                    VOUT=LDO_OUT ──FB1── V_ANALOG
                                                          │
XIAO 3V3 ──────────────────────────────────────────── +3V3  (digital + I2C + ADS + MAX)
XIAO 5V  ──────────────────────────────────────────── +5V   (J2, opcional)
XIAO GND ──────────────────────────────────────────── GNDD ──NT1── GNDA
```

| Red | Origen | Qué alimenta |
|-----|---|---|
| `V_BATT` | J1 pin1 | Carga del XIAO (hilo BAT+), J10, polo A del DPDT |
| `LDO_VIN` | J9 pin1 | VIN y EN del ADP150 |
| `V_ANALOG` | LDO + FB1 | MCP6004 V+, GSR/bandas 0,5 V, AD8232 VCC y SDN |
| `+3V3` | regulador del XIAO | ADS1115, MAX30102, MAX30205, pull-up I2C |
| `+5V` | pin 5V del XIAO | J2 (carga auxiliar; **no** es la vía LiPo) |
| `GNDD` / `GNDA` | un net-tie NT1 | digital vs analógico; un solo punto |

**Por qué ADS/MAX van a `+3V3` y no a `V_ANALOG`:** si se apaga el LDO con el XIAO vivo (USB), los pull-up I2C a 3,3 V **inyectarían** corriente en chips apagados por los diodos ESD de SDA/SCL (back-power). Decisión correcta. Efecto secundario: PPG y temperatura **siguen vivos** con “analógico off” si el XIAO tiene USB o batería.

**ADP150:** TSOT-23-5, pata 4 **NC** (no BYP, no 1 nF). C1~1 µF en VIN, C2~1 µF en VOUT, luego FB1 (600 Ω @ 100 MHz) y C4 10 µF hacia `V_ANALOG`. EN atado a VIN: el LDO vive solo si hay `LDO_VIN`.

**DPDT de caja (J9)** — 4 hilos, **no** debe cortar la carga:

| J9 | Seda | Net | Polo |
|----|---|-----|---|
| 1 | ANALOG | `LDO_VIN` | A — a BAT en ON |
| 2 | BAT | `V_BATT` | A |
| 3 | SLEEP | `SLEEP_N` | B — a GND en OFF |
| 4 | GND | `GNDD` | B |

OFF: polo B cierra `SLEEP_N` a masa → el firmware entra en deep sleep. ON: `SLEEP_N` flota (pull-up interno GPIO4). **Riesgo de uso:** un DPDT mal cableado puede dejar el LDO siempre on, o cortar BAT+ del XIAO (entonces no carga). No hay fusible ni MOSFET de protección de polaridad en `V_BATT`.

---

## 4. Microcontrolador (U1)

Seeed **XIAO ESP32-S3** en **zócalo**, no soldado por JLCPCB.

- Zócalo: **2 × tira hembra 1×7**, paso **2,54 mm**, distancia entre filas **17,78 mm**. Partir tiras de 40 pines. Macho en el módulo si viene desnudo.
- Pad 15 `BAT+` en la PCB: hilo corto al pad BAT+ de **debajo** del XIAO. Sin ese hilo no hay carga ni medida de batería por el camino previsto.
- Antena: **U.FL + cable** de la bolsa Seeed. Sin cable el BLE es muy flojo.

### Mapa zócalo ↔ Seeed ↔ firmware

USB hacia la seda `USB` (Y menor). Izquierda = pines 1–7; derecha = 14…8.

| Pad PCB | Seeed | GPIO (S3) | Net | Firmware |
|---|---|---|-----|---|
| 1 | D0 / A0 | GPIO1 | `VBAT_DIV` | `A0`, `analogReadMilliVolts * 2` |
| 2 | D1 | GPIO2 | — | libre |
| 3 | D2 | GPIO3 **strapping** | — | **prohibido para sleep** |
| 4 | D3 | GPIO4 | `SLEEP_N` | `D3`, ISR FALLING, deep-sleep EXT0 nivel 1 |
| 5 | D4 SDA | GPIO5 | `SDA` | Wire |
| 6 | D5 SCL | GPIO6 | `SCL` | Wire 400 kHz |
| 7 | D6 TX | | — | libre |
| 8 | D7 RX | | — | libre |
| 9 | D8 | | `ECG_LOP` | `D8` leads-off + |
| 10 | D9 | | `ECG_LON` | `D9` leads-off − |
| 11 | D10 | | — | libre |
| 12 | 3V3 | | `+3V3` | |
| 13 | GND | | `GNDD` | |
| 14 | 5V | | `+5V` | |
| 15 | BAT+ (no es pin de tira) | | `V_BATT` | |

Divisor de batería **en PCB:** R1 47 kΩ (`V_BATT` → `VBAT_DIV`) y R2 47 kΩ (`VBAT_DIV` → `GNDD`). Relación 1/2. El comentario del firmware (“divisor 1/2 **en el XIAO**”) es **engañoso**: en esta placa el divisor es R1/R2. El S3 no replica el divisor interno del XIAO ESP32-C3. `analogReadMilliVolts(A0)*2` es coherente **solo** con ese 1/2 de placa. Calibrar con un polímetro: offset del ADC del S3 y tolerancia 1 % de R1/R2.

Pull-up I2C: **R7, R8 = 2,2 kΩ** a `+3V3`.

---

## 5. Referencia 0,50 V y MCP6004 (U3)

Desde `V_ANALOG` ≈ 3,3 V:

- R3 **56 kΩ** y R4 **10 kΩ** → `VREF_DIV` ≈ 3,3 × 10/(56+10) = **0,500 V**.
- **Intención de diseño:** R3 y R4 a **0,1 %** (CSV del repo: C4257433 / C2507497).
- **Pedido DFM real:** R3 **C18029** (56 k, serie UNI-ROYAL) y R4 **C17902** (10 k **1 %** Basic). La referencia de GSR/bandas en las placas soldadas es peor que el papel. Documentar como **desviación as-built**.

Op-amp **MCP6004** SOIC-14, V+ = `V_ANALOG`, V− = `GNDA`.

| Unidad | Patas | Función |
|---|---|---|
| A | 1–2 unidos, 3 = `VREF_DIV` | Seguidor de la referencia 0,50 V → `N$1` / V_REF buffered. R5 **47 Ω** entre salida y C5 **4,7 µF**; la realimentación **antes** de R5 (si no, el MCP6004 oscila con 4,7 µF). |
| B | 5 = `TH_MID`, 6–7 unidos | Seguidor banda tórax |
| C | 10 = `AB_MID`, 8–9 unidos | Seguidor banda abdomen |
| D | 12 a `GNDA`, 13–14 unidos | Op-amp libre aparcado (no flota) |

---

## 6. Cadena GSR (J3)

```
V_REF 0,50 V ── R9 100 kΩ ── GSR_MID ── R11 1 kΩ ── GSR_ELEC ── J3 SIG
                     │                      │                    │
                     │                      └── D1 TVS 5 V ── GNDA
                     │
                     └── R10 470 Ω ── GSR_AIN ── ADS AIN1 (×8)
J3 GNDA ──────────────────────────────────────────────────── GNDA
```

Protección en electrodo: **R11 1 kΩ + D1 PESD5V0S1BA** (SOD-323, bidireccional). **R10 470 Ω** está entre el divisor y el ADC (no es el TVS).

**Energía en piel (orden de magnitud):** si J3 se cortocircuita, I ≈ 0,5 V / 100 kΩ = **5 µA**. No es aislamiento de paciente; solo limita corriente continua.

Firmware:

```
vMid = ADS1115 AIN1, ganancia ×8 (±0,512 V)
si vMid < 2 mV o vMid > 0,98×V_REF → gsr_uS = 0
rSkin = 100e3 * vMid / (0,50 - vMid)
gsr_uS = 1e6 / rSkin   (si rSkin ≥ 100 Ω)
```

Ganancia ×8: un GSR típico de pocos µS mueve milivoltios; ×1 se perdería en ruido. El ADS no es simultáneo: cada `readADC_SingleEnded` multiplexa.

---

## 7. Bandas de respiración (J6, J7)

Misma idea que GSR, serie **47 kΩ** (R12 tórax, R15 abdomen), electrodo `TH_ELEC` / `AB_ELEC`, TVS **D2 / D3**, 1 kΩ serie R14/R17, seguidores B/C, ADS **AIN2 / AIN3 ×1**.

El teléfono calibra min/max en ~20 s. Las tensiones van en JSON como `rt_v` y `ra_v` (voltios en el ADC), no un volumen pulmonar.

Sudor, gel y elástico mojado: la resistencia cae; no hay discriminación “banda rota vs piel húmeda”.

---

## 8. ECG (J8 + AD8232 de terceros)

Seis pads 2,54 mm + agujero de alivio. **Seda “3V3” = `V_ANALOG`**, no el pin 3V3 del XIAO. Así el módulo se apaga con el LDO.

| Pad | Net | Uso en el módulo típico |
|-----|-----|---|
| 1 | `V_ANALOG` | VCC |
| 2 | `GNDA` | GND |
| 3 | `ECG_OUT` | OUTPUT → R18 1 kΩ → `ECG_AIN` → ADS AIN0 ×1 |
| 4 | `ECG_LOP` | LO+ → D8 |
| 5 | `ECG_LON` | LO− → D9 |
| 6 | `V_ANALOG` | SDN (activo en alto; off con analógico off) |

Electrodos **solo** en el AD8232, no en la Paca. El JSON `ecg_mv` es **mV en el pin del ADS** (`volts * 1000`), no milivoltios fisiológicos de superficie. Cadencia: el `loop` llama `sampleEcg()` lo más rápido que multiplexa el ADS, pero el JSON sale cada **200 ms** con como máximo **8** muestras (`ECG_N`). Eso **no** es un ECG clínico (aliasing, huecos, sin filtro digital de red 50 Hz en firmware). `lo=1` si LO+ o LO− están en alto (electrodos mal / despegados), según el módulo.

**ESD en J8:** no hay TVS en la Paca para OUTPUT/LO. Se confía en el módulo barato. Insuficiente si se toca OUTPUT con el dedo a la placa.

---

## 9. ADS1115 (U4) — I2C 0x49

VSSOP-10 (IDGSR), VDD = `+3V3`, GND = `GNDA` (mezcla deliberada: ADC analógico con I2C digital).

| Pata | Función | Net |
|---|---|-----|
| 1 ADDR | a VDD → **0x49** | `+3V3` (MAX30205 es 0x48; no chocan) |
| 2 ALERT | sin usar en firmware | `ADS_ALERT` |
| 3 GND | | `GNDA` |
| 4 AIN0 | ECG ×1 | `ECG_AIN` |
| 5 AIN1 | GSR ×8 | `GSR_AIN` |
| 6 AIN2 | tórax ×1 | `TH_AIN` |
| 7 AIN3 | abdomen ×1 | `AB_AIN` |
| 8 VDD | | `+3V3` |
| 9 SDA / 10 SCL | | bus |

Datasheet TI: ADDR a VDD = 1001001b = 0x49. Firmware `ADDR_ADS = 0x49`, 860 SPS, gana ×8 solo el instante de GSR y vuelve a ×1.

`ADS_ALERT` no va a un GPIO: oportunidad perdida para DRDY (muestreo más limpio).

---

## 10. PPG y temperatura (J4, J5)

Pads 4P: `+3V3`, `GNDD`, `SDA`, `SCL`. Cables soldados, no bornes. C10/C11 100 nF locales.

| Módulo | Dirección | Notas |
|---|---|---|
| MAX30102 | 0x57 | LED IR/rojo; HRV **no** en placa. Umbral dedo: IR ≥ 20 000 cuentas. |
| MAX30205 | 0x48 | Registro 0x00, °C = raw × 0,00390625 |

Cables I2C largos + 400 kHz + 2,2 kΩ: margen pobre (capacidad, diafonía con LED del MAX30102). No hay series 22–100 Ω ni TVS en SDA/SCL de J4/J5.

---

## 11. Conectores restantes y polaridad

| Ref | Pieza as-built | Pines |
|-----|---|---|
| J1 | JST-PH 2P C173752 | 1 `V_BATT`, 2 `GNDD` |
| J2 | igual | 1 `+5V`, 2 `GNDD` |
| J10 | igual | paralelo J1 |
| J3/J6/J7 | KF128R-5.08-2P C475082 (DFM) | SIG / GNDA |
| J9 | JST-PH 4P C157926 | §3 |

U1 **no** está en el DFM (45 piezas, todas top). THT = `manualWeld` (ola/mano). SMD = `smtWeld`.

**Polaridad chips (ya revisada en visor 2D JLCPCB):** triángulo de seda = pata 1 de U2/U3/U4 alineada con el marcador morado de fábrica. CPL cliente U2/U3=180°, U4=270°; el ingeniero guarda otros ángulos internos de máquina. **La verdad de pata 1 es seda + 2D**, no el 3D morado.

D1–D3 son TVS **bidireccionales**: el sentido del cuerpo importa poco.

---

## 12. ESD, transitorios y lo que *no* hay

**Hay (v1.0):**

- TVS 5 V bidir en GSR, tórax, abdomen (D1–D3) + 1 kΩ serie.
- 1 kΩ entre ECG_OUT y ADS (R18): no es ESD de electrodo.
- Planos GND; vias tented.

**No hay:**

- Aislamiento galvánico USB ↔ piel (el fallo de seguridad **número 1**).
- TVS / resistencias serie en J4/J5 (I2C), J8 (salvo R18), J9 `SLEEP_N`, J1 `V_BATT`.
- CMC ni filtro de red en USB (el USB ni siquiera sale a la Paca; está en el XIAO).
- Fusible PTC en batería (se delega en la PCB de la LiPo).
- Protección de polaridad J1.
- Descarga de cinta / carcasa a tierra de chasis (caja de plástico prevista).
- IEC 61000-4-2 ensayado. Los TVS SOD-323 PESD5V0S1BA ayudan a contactos en bornes; **no** convierten esto en equipo de paciente.

GNDA y GNDD unidos en NT1: un ESD en J3 recorre el net-tie hacia el XIAO. Mejor que un único plano sucio, peor que un isolator.

---

## 13. Firmware analizado — V1.2 para la PCB fabricada

El sketch que se analizó en esta sección es `firmware/PinaBiosensor_Firmware_v1_2/PinaBiosensor_Firmware_v1_2.ino`. Su formato de frames, comandos y UUID se define en `docs/firmware_v1_2_protocol.es.md`. El sketch vigente V1.3 se describe en `firmware/README.es.md` y `docs/firmware_v1_3_protocol.es.md`. La arquitectura usa una tarea para ADS1115, otra para PPG, otra para telemetría lenta y una para comunicaciones. No se usa hardware V2.

El firmware conserva `PinaBiosensor`, ECG y PPG RAW, telemetría, eventos y HRS. JSON v4 es solo depuración.

---

## 14. Seguridad de uso (normativa: ninguna)

Ya dicho: no sanitario. Añadir para el revisor:

- Corriente GSR limitada por 100 kΩ, **pero** un fallo del ADP150 a 3,3 V en el borne (R9 abierta, soldadura puente) podría aplicar ~3,3 V a piel a través de 1 kΩ → miliamperios. No hay detección de fallo de V_REF.
- AD8232 de AliExpress: calidad de aislamiento **desconocida**.
- LiPo: solo “con PCB de protección” en la celda. JST pin1 = +.
- Olor a quemado: USB y batería fuera; no basura doméstica si hay celda.

---

## 15. As-built vs intención (fábrica)

| Ítem | Papel / CSV repo | DFM `SMT026091261919` |
|---|---|---|
| U1 zócalo | 2×1×7 | **No colocado** |
| U2/U3/U4 | C29149 / C1346056 / C37593 | Igual |
| R3 56 k 0,1 % | C4257433 | **C18029** (56 k, no 0,1 % Vishay) |
| R4 10 k 0,1 % | C2507497 | **C17902** (10 k **1 %**) |
| J3/J6/J7 | emparejar | **C475082** KF128 5,08 mm |
| Piezas | | 45, solo top |

Producción PCB (`ok/ko`): contorno útil **110 × 70 mm**. Confirmar pata 1 U2/U3/U4 en 2D (hecho: morado = triángulo).

---

## 16. Crítica y mejoras (prioridad)

Esto es lo que un revisor debe atacar. Varios fallos son **nuestros**, no del usuario.

### P0 — seguridad y “no mientas con la señal”

1. **USB y piel comparten GND.** Sin isolator USB, sin BLE-only lockout por hardware. Mejora: opto/isolator USB **o** (más barato y honesto) un **interlock**: MOSFET que corte `V_ANALOG` y las líneas de electrodo si VBUS del XIAO está presente; o documentar en seda enorme “NO USB + PIEL”. El firmware no detecta VBUS.

2. **ESD incompleta.** TVS solo en tres bornes de goma/piel. Faltan: I2C J4/J5 (TVS 3,3 V + 22–47 Ω serie), `SLEEP_N`, `ECG_OUT`/`LO±` en J8 o en el propio AD8232, TVS de 5,5–6 V en `V_BATT`. Clasificación 61000-4-2 contacto 8 kV como **objetivo de prototipo**, no de certificado.

3. **ECG y GSR en el mismo ADS multiplexado** + JSON 5 Hz + 8 muestras. O un segundo ADC / AFE para ECG, o quitar el ECG de esta placa y dejar el AD8232 en un canal dedicado (SPI AFE). Mientras tanto, describir el ECG como “forma de onda de laboratorio”.

4. **Antena v1.0.** Cobre bajo el XIAO. Uso: cable U.FL fuera. Próximo PCB: USB en un borde **y** U.FL/antena en un recorte **sin cobre** en todas las capas (el v1.1 actual solo vacía bajo el USB: **insuficiente**).

### P1 — analogía y energía

5. **R3/R4 0,1 %** como en el CSV, o medir y guardar ganancia GSR en NVS. As-built 1 % en R4 tuerce el 0,50 V.

6. **Inyección de carga del mux ADS** al cambiar ×8/×1. Leer GSR dos veces y tirar la primera; o dos ADS; o PGA externo fijo.

7. **I2C:** 100 kHz por defecto con cables >10 cm; series 33 Ω; pull-up 4,7 k si la capacitancia es baja, o buffer. Conector JST-SH 4P en vez de pads desnudos (strain relief ya hay agujero).

8. **Fusible / p-FET** en `V_BATT` (polaridad y cortocircuito del arnés J9).

9. **SLEEP y LDO en el mismo DPDT:** un error de cable deja analógico on y MCU dormido, o al revés. Mejor: un solo polo “sistema” + load switch con slew, y `SLEEP_N` generado en placa.

10. **MAX30102 y MAX30205 siguen on** con USB. Gate con MOSFET desde `V_ANALOG` o GPIO si se quiere “off de verdad”.

11. **`ADS_ALERT` a un GPIO** (no strapping) para muestreo por DRDY.

12. **Filtro RC / notch 50 Hz** en firmware para bandas y GSR (media móvil mínima). Watchdog I2C.

13. **Medida de batería:** calibrar; no fiarse del comentario “divisor en el XIAO”. Opcional ADC del XIAO BAT vs solo R1/R2: no duplicar.

### P2 — layout, DFMA, firmware de producto

14. **Seda J8 “3V3”** → `VANA` / `ANALOG 3V3` para no cablear el 3V3 digital al AD8232.

15. **Keepout U.FL** y silkscreen “ANTENA CABLE AQUÍ / NO METAL”.

16. **Pines GPIO libres** (D1, D2, D6, D7, D10): pull-down en HW o `INPUT_PULLDOWN` en FW (ahora flotan).

17. **Bonding BLE / MAC fijo** si se usa fuera de la mesa. JSON con `seq` y checksum.

18. **CPL vs visor 3D:** el 3D de JLCPCB **no** certifica pata 1. Procedimiento: 2D + triángulo. No repetir la caza de 180°.

19. **v1.1 RF ya generado** no debe usarse como “antena fuera” sin mover el extremo BAT+/U.FL al borde o recortar cobre ahí.

20. **Documentación cruzada:** `docs/01_revision.md` llama “v1.1” a cambios **eléctricos** que ya están en la v1.0 pedida. El layout v1.1 es otra cosa. Renombrar en una pasada de docs para no envenenar al siguiente LLM.

### Lo que sí está bien (no tirar)

- Sleep en **GPIO4**, no GPIO3.
- I2C sensors en `+3V3` (anti back-power).
- Snubber R5+C5 en V_REF.
- ADDR ADS a VDD (0x49) vs temp 0x48.
- TVS en los tres bornes de piel/goma (aunque no baste).
- DPDT que **no** corta carga si se cablea como §3.
- Protocolo binario V1.2 (0x12) + 0x180D.
- Contorno 110×70 real en Gerber de producción.

---

## 17. Fuera de este documento

No incluye:

- Pasos KiCad para Grok (mover XIAO, keepout U.FL, re-anclar conectores). Eso es el **siguiente** encargo, con esta spec como contrato.
- Esquemático dibujado (está en `hardware/archive/PinaBio_v1.0/PinaBiosensor_Mini.kicad_sch`).
- Los clientes BLE externos deberán interpretar el protocolo V1.2.

---

## 18. Trazabilidad para el revisor

| Afirmación | Dónde comprobarla |
|---|---|
| Pines U2/U3/U4 / XIAO | PCB archive pads vs datasheet Analog / Microchip / TI / Seeed wiki |
| Contorno 110×70 | `exports/PinaBio_v1_gerbers.zip` Edge_Cuts; ZIP producción `ok/ko` |
| Firmware | `.ino` citado; no hay otra rama de FW en este texto |
| DFM 45 piezas | pedido SMT026091261919 / visor share JLCPCB |
| Seguridad USB | `docs/04_seguridad.md` |

**Autor de esta spec:** el mismo agente que participó en el layout v1.0, el CPL, el pedido y el firmware. Hay sesgo. Los P0–P2 existen para que un segundo modelo **no** acepte el diseño por inercia.

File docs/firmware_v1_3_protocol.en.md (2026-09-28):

# Firmware PinaBiosensor 1.3 — protocol (English)

This specification is for fabricated PinaBio Paca v1.0 and sketch `firmware/PinaBiosensor_Firmware_v1_3/PinaBiosensor_Firmware_v1_3.ino`.

**Wire format is identical to firmware 1.2.** The version byte remains **`0x12`**. Receivers that already accept 1.2 must keep accepting `0x12`. Do not require `0x13`.

Full frame layout, UUIDs, CRC, MTU rules, commands and sleep behaviour: [`firmware_v1_2_protocol.en.md`](firmware_v1_2_protocol.en.md). Firmware 1.2 sources stay in the tree.

## 1.3 differences (commands / STATUS only)

- Boot serial line: `PinaBiosensor firmware v1.3 ... READY`.
- `STATUS` / `DIAG` prefix fields: `fw=1.3 proto=0x12` then the 1.2 fields.
- `STOP` clears the MCU beat preview (HR/RR become 0). Binary telemetry after STOP is not produced because acquisition is stopped.
- `ERR START_LOCK`, `ERR DEFAULTS_LOCK`, `ERR PPG_RATE_LOCK` if `stateMutex` cannot be retaken after I²C. Rare.
- `ERR SLEEP_IN_PROGRESS` when sleep starts during the unlocked part of `START`; acquisition remains stopped.
- `ERR PPG_CONFIG_UNVERIFIED` blocks `START` after an unverified PPG configuration or rollback. `ERR PPG_UNAVAILABLE` rejects a rate change when PPG is unavailable.
- `SET PPG_RATE` / `DEFAULTS` still require `STOP`. On failure, a verified rollback retains the previous hardware rate. If rollback also cannot be verified, PPG becomes unavailable until reboot and successful setup.

There is **no** `CONFIRM_SKIN_SESSION` and **no** `ERR USB_SKIN_INTERLOCK`. This PCB cannot sense USB VBUS. Skin sessions: battery + BLE. Charge (including power bank) and flash with electrodes off.

Sketch 1.2 remains at `firmware/PinaBiosensor_Firmware_v1_2/` for rollback.

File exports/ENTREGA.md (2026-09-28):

# Entrega — PinaBio v1.0 (adaptación caja)

> **Paquete del pedido restaurado en `main` (28-09-2026).** `exports/PinaBio_v1_gerbers.zip`, BOM y CPL coinciden con los SHA-256 de `exports/archive_v1.0/SHA256SUMS`. Comprueba los hashes antes de repetir el pedido. No usar `exports/gerbers/` como sustituto.

Producto: **PinaBio v1.0**. Gerbers para pedir: `exports/PinaBio_v1_gerbers.zip` (copia byte a byte de `PinaBiosensor_Completa_gerbers.zip`; no se regeneró cobre).

Fecha: 2026-09-12  
Para: Alejandro

## Qué cambió (caja)

1. **Eliminado SW1** (slide `SW_CK_JS202011CQN_DPDT_Straight`) del esquemático y de la PCB.
2. **J9 INT CAJA** — JST-PH 4P (`JST_PH_S4B-PH-K_1x04_P2.00mm_Horizontal`) para DPDT de panel:
   - 1 ANALOG → `LDO_VIN`
   - 2 BAT → `V_BATT`
   - 3 SLEEP → `SLEEP_N`
   - 4 GND → `GNDD`
3. **J10 BATT METER** — JST-PH 2P (misma familia que J1), paralelo a J1 (`V_BATT` / `GNDD`), zona libre cerca del borde inferior izquierdo.
4. Esquemático con símbolos reales Conn_01x04 / Conn_01x02; nota de título: panel DPDT vía J9; fábrica no monta slide.
5. BOM, docs `08_pedido_jlcpcb.md` y `09_caja_interruptor_medidor.md` actualizados.

## Congelado respetado

- Sleep en **D3/GPIO4**
- I2C a **+3V3**
- ADP150 pin4 = **NC** (sin C3 BYP)
- Un solo NT1; GSR / bandas / ECG sin cambios
- Tamaño placa **110 × 70 mm**
- Camino de carga BAT del XIAO **no cortado**

## DRC

**0 errores / 0 unconnected** (`exports/drc_final.json`, `exports/drc_report.txt`).

## Exports

- Gerbers: `exports/gerbers/` + ZIP `exports/PinaBio_v1_gerbers.zip` (alias: `PinaBiosensor_Completa_gerbers.zip`)
- CPL JLCPCB: `exports/PinaBio_v1_cpl.csv` (alias: `PinaBiosensor_Completa_cpl.csv`)
- BOM JLCPCB: `exports/PinaBio_v1_bom_jlc.csv` (alias: `PinaBiosensor_Completa_bom_jlc.csv`)
- BOM diseño + LCSC: `bom/BOM.csv`
- 3D: `exports/pcb_3d_caja.png` (también `pcb_3d_caja_iso.png`)

## Ensamblaje

Soldar todo SMD (incl. ADS1115), zócalo XIAO, J1, J2, **J10**, bornes J3/J6/J7, conector **J9**.  
**No montar** slide SW1 — el DPDT va en el panel de la caja (4 hilos a J9).

Ver `docs/09_caja_interruptor_medidor.md` y `docs/08_pedido_jlcpcb.md`.

**No es un dispositivo médico.** Sesión con piel: solo Bluetooth, USB del PC desconectado.

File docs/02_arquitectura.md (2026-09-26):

# Arquitectura — PinaBio v1.0

Una sola placa (antes se llamaba «Completa» en docs; es este mismo diseño). La Mini queda sustituida.

**No es un dispositivo médico.** Sesión con electrodos o bandas: **Bluetooth, USB del PC desconectado**.

## Qué hay

| Sensor | Cómo |
|---|---|
| GSR | Borne J3, igual que antes (0,5 V, 100 kΩ) |
| PPG / pulso | MAX30102 en J4 (pads) |
| Temperatura | MAX30205 en J5 (pads) |
| ECG | Módulo AD8232 en J8 (6 pads). Electrodos van al módulo, no a nuestra PCB |
| Respiración pecho | Goma elástica resistiva, borne J6 |
| Respiración abdomen | Igual, borne J7 |
| Batería | Carga USB-C del XIAO; voltios en A0; % en el teléfono |

Bandas: 0,5 V → 47 kΩ → goma → masa. El op-amp B/C copia el punto medio. El teléfono **calibra** la profundidad (no son litros de aire).

## ADS1115

| Canal | Ganancia | Señal |
|---|---|---|
| AIN0 | ×1 | ECG |
| AIN1 | ×8 | GSR |
| AIN2 | ×1 | Pecho |
| AIN3 | ×1 | Abdomen |

AD8232 SDN unido a V_ANALOG: con SW1 OFF se apaga el ECG junto al analógico. LO+ / LO− → D8 / D9.

## BLE

Nombre BLE `PinaBiosensor` (no es el nombre de marketing). Protocolo binario V1.1 + servicio de pulso 0x180D. JSON v4 opcional para depuración.

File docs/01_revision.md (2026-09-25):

# Revisión de la arquitectura original (LLM → v1.1)

La dirección del Mini (GSR + PPG + temperatura, sin ECG ni respiración) es razonable. Estos puntos **sí** había que cambiarlos antes de fabricar.

## Errores o riesgos reales

1. **Back-power por I2C.** Si el ADS1115 (y los sensores) se alimentan de V_ANALOG y los pull-up de I2C van a 3.3 V del XIAO, con el interruptor “off” y el USB conectado el micro sigue vivo y mete corriente en chips apagados por los diodos ESD de SDA/SCL. **v1.1:** ADS1115, MAX30102 y MAX30205 se alimentan de `+3V3`. V_ANALOG queda para GSR, V_REF y el MCP6004.

2. **GPIO3 es pin de strapping del ESP32-S3.** Si SW1 lo pone a GND al apagar, un reset o un USB con el interruptor off puede impedir el arranque. **v1.1:** *sleep* en **D3 / GPIO4**.

3. **4.7 µF colgado de la salida del MCP6004.** Ese op-amp no está pensado para capacitancias grandes; oscila y ensucia V_REF. **v1.1:** R5 = 47 Ω entre salida y C5; la realimentación se toma *antes* de R5.

4. **R_series 47 Ω no es protección ESD.** Frente a la piel (decenas de kΩ) no hace casi nada y no sujeta un transitorio. **v1.1:** 1 kΩ + TVS 5 V (D1) en el electrodo.

5. **Canales ADC sin usar.** Dejar AIN0/2/3 al aire capta ruido. **v1.1:** a GNDA.

6. **Condensadores del ADP150.** El datasheet pide ~1 µF en VIN y VOUT; el BYP lleva 1 nF. El filtro ferrita+10 µF va *después*.

7. **MAX30102 a V_ANALOG con GND digital.** Los pulsos del LED vuelven por el net-tie y se cuelan en el GSR. **v1.1:** VCC del módulo a `+3V3`.

8. **Pad BAT del XIAO no está en el zócalo 2×7.** Hay que un hilo del pad 15 de la PCB al pad BAT+ del módulo. Sin eso no hay carga ni batería.

9. **USB + electrodos.** No hay aislamiento de paciente. Ver `04_seguridad.md`.

10. **Guía KiCad:** “etiqueta jerárquica global” no existe; se usan **etiquetas globales** o símbolos de *power*. El net-tie tiene que estar también en el esquemático, no solo en la PCB.

## Lo que se mantuvo porque está bien pensado

- XIAO en zócalo, carga por el propio módulo, SW1 no corta la ruta de carga.
- V_REF 56k/10k → 0.50 V desde 3.3 V.
- Ganancia ×8 del ADS1115 (±0.512 V) para GSR.
- Planos GNDA/GNDD y un solo net-tie.
- Canales B/C/D del MCP6004 en seguidor a masa.
- Terminal de tornillo para GSR y pads soldados para I2C.

## Qué no pretende ser esta placa

No sustituye un diseño sanitario (IEC 60601). Es un prototipo de laboratorio personal, con corriente de GSR muy baja (~5 µA máx. si la piel fuera un cortocircuito a través de 100 kΩ @ 0.5 V).

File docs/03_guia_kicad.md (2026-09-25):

# KiCad — guía para Alejandro (cero experiencia)

No vas a “diseñar la placa desde un folio en blanco”. Eso ya está hecho en este repositorio.

La guía vieja de otros LLM (`uploads/PinaBiosensor_Mini_Guia_KiCad_Principiantes_…`) te decía **crear un proyecto nuevo y dibujar**. **No hagas eso.** Tiene errores (pin de apagado, alimentación de sensores, nombres de menús). Aquí abres **lo que ya hay** y solo miras / compruebas.

---

## Qué te genero yo (en cristiano)

Imagina tres papeles del mismo circuito:

| Archivo | Qué es | Tú qué haces |
|---|---|---|
| `hardware/PinaBiosensor_Mini.kicad_pro` | La carpeta-proyecto. El “índice”. | Doble clic. Es lo único que abres al empezar. |
| `…kicad_sch` | El **esquemático**. Hoy es un **mapa en texto** (párrafos), no el dibujo de simbolitos de la carrera. | Lo lees. No es donde se fabrica. |
| `…kicad_pcb` | La **placa de verdad**: cobre, agujeros, sitio de cada pieza. | Aquí pasas el rato. |
| `…net` | Lista de “este pin va con este pin”. | No lo edites a mano. |
| `hardware/footprints.pretty/` | Formas de soldadura raras (zócalo XIAO, pads de los cables). | KiCad las usa solo. |
| `hardware/sym-lib/` | Símbolos nuestros. | Igual. |
| `bom/BOM.csv` | Lista de la compra (qué pieza, cuántas). | Para pedir a JLCPCB / DigiKey. |
| `exports/gerbers/` | Archivos que entiende la fábrica. | **No los subas aún** si el DRC no está limpio. |
| `exports/PinaBiosensor_Mini_pcb.svg` | Dibujo de la placa para verla en el navegador. | Echar un vistazo sin KiCad. |

**Qué no te estoy dando todavía (importante):**

- Un esquemático “bonito” con resistencias dibujadas y cables. Eso se puede hacer después, para que lo entiendas mejor. **La fábrica mira la PCB, no ese dibujo.**
- Una PCB **lista para pagar** sin que nadie mire el DRC. Las pistas las tendió un programa; pueden cruzarse o quedar justas. **No pidas 5 placas el primer día sin esa revisión.**

Si más adelante quieres, el siguiente encargo de KiCad sería: 1) dibujar el esquemático de verdad, 2) limpiar pistas hasta DRC = 0 errores, 3) Gerbers nuevos + PDF para ti.

---

## 0. Instalar KiCad (una vez)

1. Entra en [https://www.kicad.org/download/](https://www.kicad.org/download/).
2. Windows: descarga el instalador. **KiCad 8** (o 9) vale. El proyecto se hizo con formato 7; 8 lo abre.
3. Instala. Cuando pregunte por **librerías / footprints / 3D**, déjalo todo marcado. Si las quitas, faltan piezas.
4. Abre **KiCad**. Verás una ventana gris con iconos grandes: eso es el **gestor de proyectos**. No pulses “Nuevo proyecto”.

---

## 1. Abrir ESTE proyecto

1. En el gestor: **Archivo → Abrir proyecto**.
2. Ve a la carpeta del repo → `hardware` → `PinaBiosensor_Mini.kicad_pro` → Abrir.
3. A la izquierda salen los archivos del proyecto. Los dos que importan:
   - hoja / esquemático
   - placa / PCB

Si KiCad pide “migrar” o “guardar como versión nueva”: acepta y guarda **dentro de `hardware/`**, no en Documentos.

---

## 2. El esquemático (solo lectura)

1. Doble clic en el esquemático.
2. Verás **texto**. Es un resumen del circuito, no el dibujo clásico.
3. Zoom: rueda del ratón. Mover: rueda pulsada o clic medio.
4. No hace falta que dibujes nada. **Cierra** cuando te hayas leído el mapa (alimentación, GSR, I2C, XIAO).

No pulses “Añadir símbolo” ni “Hilo”. Si lo haces sin querer: **Archivo → Revertir** o cierra sin guardar.

---

## 3. La PCB (aquí está la placa)

1. En el gestor, doble clic en **PCB** (`PinaBiosensor_Mini.kicad_pcb`).
2. Verás un rectángulo (~9 × 6 cm) con pads y rayas.
3. Si las zonas de cobre (masas) se ven vacías o raras: pulsa la tecla **`B`** (rellenar zonas). Es normal.
4. Zoom y mover: igual que antes.

### Capas (el “sándwich”)

Arriba a la derecha hay casillas de capas. Para no marearte, deja visibles sobre todo:

- **F.Cu** — cobre de arriba (pistas)
- **B.Cu** — cobre de abajo
- **F.SilkS** — texto blanco (nombres J1, USB…)
- **Edge.Cuts** — el contorno de la placa

Si lo ves todo negro, desmarca capas raras (Adhesive, Courtyard) hasta que se lea.

### Vista 3D (la más útil para ti)

Menú **Ver → Visor 3D** (o Alt+3).

Ahí ves la placa como objeto. Gira con el ratón. Comprueba a ojo:

- El **USB del XIAO** hacia **fuera**, en un borde, no contra el centro.
- En **v1.1** hay un recuadro **RF KEEPOUT** junto al USB: no debe haber cobre bajo el conector USB. El BLE del ESP32-S3 va por el **U.FL + cable** (hacia `BAT+`), no por una cerámica en ese borde.
- **J1** batería: hay sitio para el conector; no está debajo del XIAO.
- **J3** tornillo GSR: en un borde, fácil de cablear.
- Dos grupos de **4 pads** (MAX30102 y MAX30205) con un agujero al lado (brida del cable).

Cierra el visor 3D. Sigues en la PCB.

---

## 4. No romper nada (manos quietas)

| Si pulsas sin querer | Qué pasa | Qué hacer |
|---|---|---|
| Clic en una pieza y arrastras | Se mueve el componente | `Ctrl+Z` ahora mismo |
| Tecla `M` | Mover | Esc, luego `Ctrl+Z` |
| Tecla `X` | Empiezas una pista | Esc |
| `Supr` | Borras | `Ctrl+Z` |

Regla de oro: **si no estás corrigiendo un error de DRC, no guardes.** Mira, `Ctrl+Z`, cierra.

---

## 5. El DRC (el examen antes de pagar)

Esto es “¿la fábrica puede hacer esta placa sin cortocircuitos?”.

1. Menú **Inspeccionar → Verificación de reglas de diseño** (DRC).
2. Dale a **Ejecutar DRC** (o similar).
3. Saldrá una lista. **Errores** = mal. **Avisos** = a veces se pueden vivir.

Qué significan, en cristiano:

- **Clearance / cortocircuito:** dos coppers se tocan y no deberían. Malo.
- **Unconnected / no conectado:** un pad que debería ir a una red se quedó en el aire. Malo.
- **Courtyard overlap:** dos piezas se pisan el “espacio personal”. A veces aceptable, a veces no.

**Hoy es normal que salgan errores.** Las pistas las tiró un script. No significa que el circuito esté mal pensado; significa que **aún no está limpio para JLCPCB**.

Anota cuántos errores hay (captura de pantalla). Eso es lo que hay que limpiar **antes** de pedir placas. Si quieres, en el siguiente paso lo hacemos juntos (tú pegas la lista o una captura).

No intentes “arreglar 40 pistas” el primer día. Es el trabajo más ingrato de KiCad.

---

## 6. Qué debes mirar tú (aunque no sepas KiCad)

Con el visor 3D y el silkscreen (texto blanco):

1. **USB** del zócalo XIAO hacia el borde de la placa.
2. Hay un **pad extra BAT+** junto al zócalo. En la vida real soldarás un **hilo corto** de ese pad al pad BAT de debajo del XIAO (el zócalo de 14 pines **no** lleva la batería).
3. **J1** dice BAT+ y GND. El conector JST no se puede meter al revés si es el bueno; aun así, **rojo = positivo**.
4. El borne GSR **lejos** del XIAO es mejor (menos ruido). Si están pegados, se puede vivir en un prototipo.
5. Los dos sensores I2C **no van soldados en esta placa**: van con cable a esos 4 pads.

---

## 7. Fabricación (solo cuando DRC esté limpio)

**Todavía no.** Cuando lo esté:

1. En PCB: **Archivo → Fabricación → Gerbers** (y taladros / drill).
2. O usas `exports/gerbers/` **regenerados ese día**, no unos viejos.
3. En JLCPCB subes el ZIP y **abres su visor Gerber**. Tienes que ver el contorno, los agujeros y las pistas. Si ves un rectángulo vacío, el ZIP está mal.
4. Pedido típico que hablamos: **5 placas**, **2 montadas** (SMD, incluido ADS1115), **3 vírgenes**. Tú sueldas zócalo, JST, interruptor, borne y cables.

---

## 8. Lo que no tienes que aprender ahora

- Crear librerías.
- Dibujar un esquemático desde cero.
- El auto-enrutador.
- Python / SKiDL (`scripts/generate_kicad.py`). Eso es cómo **yo** regenero el diseño; tú no lo necesitas para abrir KiCad.

---

## 9. Si algo sale raro

- “No encuentro footprints Pina”: abre el proyecto desde `PinaBiosensor_Mini.kicad_pro`, no arrastrando solo el `.kicad_pcb`.
- Todo blanco: tecla `B`; activa F.Cu y B.Cu.
- KiCad en inglés: **Preferences → Language → Spanish**, reinicia.
- Has tocado y no sabes qué: cierra **sin guardar** y vuelve a abrir.

---

## Resumen en una frase

Yo te genero el **proyecto KiCad ya relleno** (placa + lista de piezas + mapa). Tú instalas KiCad, **abres**, miras en **3D**, corres el **DRC** y no pides cobre hasta que esa lista de errores esté vacía. El dibujo “de carrera” del esquemático es un extra, no el primer paso.

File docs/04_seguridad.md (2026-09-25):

[English](#english) | [Español](#español)

# Safety — biofeedback prototype

This is **not** a medical / healthcare product. It does not diagnose anything.

## USB and skin (includes ECG and bands)

Everything shares USB ground. **Never** connect a PC over USB while electrodes, bands, or ECG are on the body. Charge and flash with **skin off**. A session = **Bluetooth only**.

## GSR and bands

Very low current (fractions of a volt, tens of kΩ). Not over wounds.

## ECG

Electrodes go to the AD8232 module. It is a lab toy, not a hospital electrocardiograph.

## LiPo battery

Cell **with a protection board**. JST: pin 1 BAT+, pin 2 GND.

## If it smells burnt

USB out, battery out, not in household trash.

---

# Seguridad — prototipo de biofeedback

Esto **no** es un producto sanitario. No diagnostica nada.

## USB y piel (incluye ECG y bandas)

Todo comparte masa con el USB. **Nunca** un PC por USB con electrodos, bandas o ECG puestos. Cargas y programas con la piel **fuera**. Sesión = **solo Bluetooth**.

## GSR y bandas

Corriente muy baja (décimas de voltios y decenas de kΩ). No sobre heridas.

## ECG

Los electrodos van al módulo AD8232. Es un juguete de laboratorio, no un electrocardiógrafo de hospital.

## Batería LiPo

Celda **con placa de protección**. JST: pin 1 BAT+, pin 2 GND.

## Si huele a quemado

USB fuera, batería fuera, no a la basura normal.

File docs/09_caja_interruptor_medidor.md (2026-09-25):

# Caja: interruptor DPDT de panel + medidor de batería

PinaBio v1.0 adaptada para **caja**: el slide SW1 ya no se monta en la PCB.
El encendido/apagado va en un **DPDT de panel** cableado a **J9**. El medidor de batería usa **J10**.

## J9 — INT CAJA (JST-PH 4 pines)

Conector en la PCB: `JST_PH_S4B-PH-K` horizontal. Sedas: **J9: INT CAJA**, pines 1–4.

| Pin J9 | Seda | Net PCB | Cable al DPDT de panel |
|---|---|---|---|
| 1 | ANALOG | LDO_VIN | Polo A — lado “alimentación analógica / LDO” |
| 2 | BAT | V_BATT | Polo A — lado batería |
| 3 | SLEEP | SLEEP_N | Polo B — señal sleep (activo al GND) |
| 4 | GND | GNDD | Polo B — masa |

### Cableado del DPDT de panel (4 hilos)

Misma lógica que el antiguo slide:

1. **Polo A (ON = enciende analógico):** une **BAT (pin 2)** ↔ **ANALOG (pin 1)**  
   → En ON: `V_BATT` alimenta `LDO_VIN`.
2. **Polo B (OFF = sleep):** une **SLEEP (pin 3)** ↔ **GND (pin 4)**  
   → En OFF: `SLEEP_N` a masa (duerme). En ON: ese polo queda abierto.
3. Los contactos “extras” del DPDT (equivalentes a pines 3 y 6 del slide viejo) **no se usan** (N/C en el arnés).

**No cortes** el camino de carga BAT del XIAO (sigue por su propio hilo/pads).

Pistas de potencia en PCB ≥ 0,45 mm.

## J10 — BATT METER (JST-PH 2 pines)

Paralelo a **J1** (LiPo):

| Pin J10 | Net | Uso |
|---|---|---|
| 1 | V_BATT | Positivo batería / medidor |
| 2 | GNDD | Masa |

Seda: **J10: BATT METER**. Sirve para enchufar un voltímetro / monitor de batería sin desconectar J1.

## Fábrica / ensamblaje

- Montar **J9** y **J10** (y el resto SMD + zócalo XIAO + J1/J2 + bornes).
- **No montar** el slide SW1.
- El DPDT y el cable de 4 hilos van en la **caja** (panel).

## Seguridad

No es un dispositivo médico. Con electrodos en piel: solo Bluetooth; USB del PC desconectado.

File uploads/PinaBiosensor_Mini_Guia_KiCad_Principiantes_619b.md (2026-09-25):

# Guía de KiCad para Principiantes — PinaBiosensor Mini

Esta guía asume que **no has usado KiCad nunca**, pero que sí entiendes conceptos de electrónica (aunque estén algo oxidados). No es un manual genérico de KiCad: está escrita paso a paso para diseñar exactamente la placa descrita en `PinaBiosensor_Mini_Arquitectura_Hardware.md`.

---

## 1. Conceptos previos (el "vocabulario" de KiCad)

Antes de abrir el programa, cuatro ideas que necesitas tener claras:

- **Esquemático vs. PCB**: son dos vistas distintas del mismo circuito. El **esquemático** es el dibujo conceptual con símbolos (como los que usabas en la carrera: resistencias, chips, líneas de conexión). La **PCB** es el diseño físico real: rectángulos de cobre (pads), pistas, y la forma física de la placa. KiCad mantiene ambas sincronizadas.
- **Símbolo vs. Footprint (huella)**: el símbolo es el dibujo esquemático de un componente (por ejemplo, un rectángulo con patillas para el ADS1115). El footprint es la geometría física que se solda en la PCB (los pads reales, con sus medidas en milímetros). Un mismo símbolo puede tener varios footprints posibles (por ejemplo, el mismo chip en encapsulado DIP o SOIC).
- **Red (Net)**: un conjunto de pines que están eléctricamente conectados entre sí (por ejemplo, todos los puntos que forman "GNDA" son una sola red). Cuando dibujas una línea entre dos pines en el esquemático, estás diciendo "estos pines pertenecen a la misma red".
- **ERC y DRC**: dos verificadores automáticos. **ERC** (Electrical Rules Check) revisa el esquemático (pines sin conectar, conflictos de dirección de señal). **DRC** (Design Rules Check) revisa la PCB física (pistas demasiado juntas, espaciados no fabricables). Ejecutar ambos antes de dar por bueno un diseño es obligatorio, no opcional.

---

## 2. Instalación

1. Descarga KiCad (versión 8.x o superior) desde **kicad.org** — hay instalador para Windows, macOS y Linux.
2. Durante la instalación, acepta también instalar las **librerías estándar** (símbolos, footprints y modelos 3D) — es la opción por defecto, no la desmarques.
3. Abre KiCad. Verás el **Gestor de Proyectos** (KiCad Project Manager) — es la ventana desde la que se crean y organizan los proyectos.

---

## 3. Crear el proyecto

1. Gestor de Proyectos → `Archivo` → `Nuevo Proyecto`.
2. Nombra el proyecto, por ejemplo `PinaBiosensor_Mini`, y elige una carpeta. KiCad creará varios archivos (`.kicad_pro`, `.kicad_sch`, `.kicad_pcb`) — no los edites a mano, siempre desde el programa.
3. Haz doble clic en el icono de **Editor de Esquemáticos** dentro del proyecto. Empezamos aquí.

---

## 4. Librerías que vas a necesitar

Todas las librerías estándar de KiCad vienen instaladas, pero dos componentes de este proyecto no están en las librerías oficiales y hay que añadirlos como **librerías de terceros**:

- **XIAO ESP32-S3**: busca en internet "Seeed XIAO ESP32S3 KiCad library" — Seeed Studio publica una librería oficial en GitHub con símbolo y footprint del zócalo `Conn_01x07` ya orientado correctamente.
- **MAX30102 (módulo/breakout)**: si usas un módulo comercial (breakout) en vez del chip desnudo, busca "MAX30102 breakout KiCad footprint" — normalmente solo necesitas un footprint de 4 pads en línea, no hace falta el símbolo exacto del fabricante: puedes usar un símbolo genérico de 4 pines (`Conn_01x04`) y renombrar los pines a VCC/GND/SDA/SCL.
- **MAX30205**: igual que el anterior, si usas el chip en SOIC-8 tienes footprint estándar en la librería `Package_SO`; si usas un breakout, aplica el mismo truco del `Conn_01x04`.

**Cómo añadir una librería de terceros** (lo harás 1-2 veces):
1. Descarga el archivo `.zip` del repositorio y descomprímelo.
2. En el Editor de Esquemáticos: `Preferencias` → `Gestionar Símbolos` → `Añadir librería existente` → apunta al archivo `.kicad_sym`.
3. Repite lo mismo para footprints en `Gestionar Footprints`, apuntando al archivo `.pretty` (una carpeta con extensión `.pretty`).

---

## 5. Dibujar el esquemático, bloque a bloque

Trabaja siguiendo el documento de arquitectura, bloque por bloque, ejecutando ERC después de cada uno. Es mucho más fácil depurar 5 errores que 50.

### 5.1 Colocar el XIAO
- Herramienta "Colocar símbolo" (icono de chip con un `+`, o tecla `A`). Busca el símbolo del XIAO ESP32-S3.
- Colócalo en el centro del lienzo. Es el punto de referencia del resto del circuito.

### 5.2 Alimentación
- Coloca símbolos de "power flags" para las redes globales (`VBAT`, `+3V3`, `V_ANALOG`, `GNDA`, `GNDD`): en KiCad, en vez de dibujar cables largos por todo el esquemático, se usan **etiquetas globales** (`Colocar` → `Etiqueta jerárquica global`, o el atajo con la tecla que asignes) con el mismo nombre de red — dos pines con la misma etiqueta global están conectados aunque no tengan ninguna línea dibujada entre ellos. Es la forma limpia de manejar redes de alimentación.
- Coloca el LDO ADP150 (búscalo por nombre en el buscador de símbolos), la ferrita, el condensador de 10µF, y conéctalos según el documento de arquitectura: V_BATT → LDO → filtro LC → V_ANALOG.
- Divisor del monitor de batería: dos resistencias de 47kΩ en serie entre V_BATT y GND, con el punto medio a una etiqueta local que luego unirás al pin A0 del XIAO.
- Divisor V_REF: resistencias de 56kΩ y 10kΩ desde V_ANALOG, punto medio a la entrada no inversora del canal A del MCP6004.

### 5.3 MCP6004 (op-amp)
- Coloca el símbolo del MCP6004 (viene en la librería `Amplifier_Operational`).
- Canal A: entrada no inversora = punto medio del divisor V_REF; realimentación directa de salida a entrada inversora (configuración seguidor); condensador de 4.7µF de la salida a GNDA.
- Canales B, C, D (no usados): entrada no inversora a GNDA, realimentación de salida a entrada inversora igual que el canal A (ver §3.4 del documento de arquitectura — es obligatorio, no opcional, para evitar oscilaciones).
- No olvides los pines de alimentación del propio chip (V+ a V_ANALOG, V- a GNDA) — es un error muy común olvidar alimentar el símbolo del op-amp porque "parece" que solo tiene los pines de señal.

### 5.4 ADS1115
- Símbolo en librería `Analog_ADC` o similar (búscalo por nombre "ADS1115").
- `ADDR` → V_ANALOG (fija dirección `0x49`).
- `SDA`/`SCL` → bus I2C, con las resistencias pull-up de 2.2kΩ hacia el 3.3V digital del XIAO.
- `AIN1` → nodo de salida del divisor de GSR (ver siguiente bloque). Los demás canales (`AIN0`, `AIN2`, `AIN3`) quedan sin conectar — esto SÍ está permitido en un ADC (a diferencia del op-amp), pero ERC probablemente te avisará con un "warning" de pin sin conectar: es esperado, puedes marcarlo como "no conectado intencionadamente" con el símbolo de flag correspondiente (`Colocar` → `Marcador de no conexión`, una X pequeña) para que ERC no lo repita en cada verificación.

### 5.5 Circuito de GSR
- Resistencia `R_FIXED` (100kΩ) desde V_REF (salida del buffer del MCP6004) hasta el Nodo_MID.
- Desde el Nodo_MID: `R_limit` (470Ω) hacia `AIN1` del ADS1115.
- `R_series` (47Ω) desde el Nodo_MID hacia el terminal de tornillo de los electrodos.
- `C_shunt` (100nF) entre el terminal de tornillo y GNDA.
- Símbolo del terminal de tornillo: busca `Conn_01x02` con footprint de terminal de tornillo (lo verás también como "Terminal Block" en las librerías de footprints, `TerminalBlock_...`).

### 5.6 MAX30102 y MAX30205
- Para cada uno: símbolo `Conn_01x04` (o el símbolo específico si usaste la librería del fabricante), pines renombrados VCC/GND/SDA/SCL.
- VCC → V_ANALOG, GND → GNDD, SDA/SCL → mismo bus I2C que el ADS1115.
- Direcciones I2C (0x57 y 0x48) no se "dibujan" en el esquemático — son fijas de fábrica en estos sensores, no hace falta ningún pin de configuración de dirección como sí ocurría con el ADS1115.

### 5.7 Interruptor SW1 y bloque de apagado
- Símbolo de interruptor de doble contacto (o dos interruptores simples, `SW_Push` o `SW_SPST`, si no encuentras uno de doble contacto integrado — puedes representarlo con dos símbolos independientes que se accionan físicamente a la vez).
- Contacto 1: en serie en la línea V_BATT → entrada del LDO.
- Contacto 2: entre GPIO3 del XIAO y GNDD, con una resistencia de pull-up hacia 3.3V (o usa el pull-up interno del ESP32-S3 activado por firmware, como hace el `.ino` con `INPUT_PULLUP` — en ese caso no necesitas la resistencia física).

### 5.8 J_CHARGE y J_BATT
- Igual que en la versión completa: conectores directos a los pads BAT del XIAO, sin pasar por el interruptor.

---

## 6. Ejecutar ERC

`Inspeccionar` → `Verificación de reglas eléctricas`. Revisa la lista de errores/warnings uno a uno. Los más habituales para principiantes:
- **Pin de alimentación sin conducir**: olvidaste conectar V+ o V- de algún chip (op-amp, sensores).
- **Pin de entrada flotante**: alguna entrada de señal quedó sin conectar y sin marcar como "no conectada intencionadamente".

No pases a la PCB hasta que ERC esté limpio (0 errores; los warnings de "no conectado intencionadamente" que marcaste tú mismo son aceptables).

---

## 7. Asignar Footprints

`Herramientas` → `Asignar Footprints`. Para cada símbolo del esquemático, eliges qué footprint físico le corresponde. Usa la lista de la sección §4 de este documento y la tabla del BOM de la arquitectura hardware como referencia. Para las resistencias/condensadores normales, usa el tamaño SMD `0805` (buen equilibrio entre "soldable a mano" y "no ocupa demasiado sitio") salvo que prefieras `1206` si tu pulso no está muy entrenado todavía — es perfectamente válido y más cómodo para volver a soldar después de 30 años.

---

## 8. Pasar a la PCB

1. Abre el **Editor de PCB** desde el gestor de proyectos.
2. `Herramientas` → `Actualizar PCB desde Esquemático`. Verás aparecer todos los footprints amontonados en una esquina, unidos por líneas finas amarillas ("ratsnest") que representan las conexiones pendientes de enrutar.
3. Define el **contorno de la placa**: capa `Edge.Cuts`, dibuja un rectángulo (o la forma que prefieras) con la herramienta de líneas.
4. Distribuye los footprints dentro del contorno, agrupando por bloque funcional: zona de alimentación cerca del XIAO y el LDO; zona analógica (MCP6004, ADS1115, GSR) agrupada y algo alejada del XIAO; pads de sensores I2C cerca del borde de la placa (para que el cable salga cómodo).

---

## 9. Planos de masa (GNDA / GNDD)

1. `Colocar` → `Zona` (o el icono de polígono relleno).
2. Dibuja el polígono cubriendo la zona analógica, asígnalo a la red `GNDA`.
3. Repite para `GNDD` en la zona digital.
4. Entre ambas zonas, coloca el **Net-Tie** (búscalo en footprints como `NetTie-2_...`) cerca del LDO y el XIAO, tal como indica el documento de arquitectura.
5. Recuerda rellenar las zonas (`B` o el botón de "rellenar todas las zonas") para que el cobre se genere realmente — hasta que no lo haces, el plano es solo un contorno vacío.

---

## 10. Ancho de pistas (Net Classes)

`Archivo` → `Configuración de la Placa` → `Clases de Red`. Crea (o edita la clase `Default`) tres clases con los anchos indicados en el documento de arquitectura:
- Alimentación: 0.4–0.5 mm
- Analógicas: 0.25 mm
- I2C: 0.25 mm

Luego, en el esquemático o en la PCB, asigna cada red a su clase correspondiente (`Archivo` → `Configuración de la Placa` → `Clases de Red` → pestaña de asignación de redes por patrón de nombre, por ejemplo `V_*` a la clase de alimentación).

---

## 11. Enrutar las pistas

Herramienta de ruta (tecla `X` para pistas normales). Sigue el ratsnest amarillo. Consejos:
- Enruta primero alimentación y GND (ya cubierto por los planos, así que en realidad son pocas pistas explícitas).
- Mantén las pistas I2C cortas, paralelas entre sí, y sobre el plano GNDD.
- Aleja las pistas analógicas (Nodo_MID, V_REF) de las pistas I2C, tal como indica el documento de arquitectura — el I2C conmuta a alta frecuencia y puede acoplar ruido en la señal de GSR si van paralelas y cercanas.

---

## 12. Verificación final: DRC

`Inspeccionar` → `Verificación de reglas de diseño`. Revisa espaciados mínimos, pistas sin conectar, y solapamientos. No envíes la placa a fabricar hasta que DRC esté limpio.

---

## 13. Generar los ficheros de fabricación (Gerbers)

1. `Archivo` → `Fabricación` → `Gerbers`.
2. Selecciona todas las capas de cobre, máscara de soldadura, serigrafía y `Edge.Cuts`.
3. Genera también el archivo de taladros (`Drill Files`).
4. Comprime todo en un `.zip` — es lo que subirás directamente a un fabricante de PCBs (JLCPCB, PCBWay, etc.).

Con esto tienes el ciclo completo: esquemático → footprints → PCB → planos → rutado → verificación → fabricación, aplicado paso a paso a esta placa concreta.

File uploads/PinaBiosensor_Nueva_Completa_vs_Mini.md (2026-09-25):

# PinaBiosensor — Diff Técnico: Nueva "Versión Completa" (sobre base Mini)

> Documento de referencia para uso como contexto en Cursor.
> **Punto de partida**: PinaBiosensor Mini (documentado en `PinaBiosensor_Mini_Arquitectura_Hardware.md` y `PinaBiosensor_Mini_Firmware.ino`).
> **Esta nueva "Completa" sustituye conceptualmente a la v1.0 original** (la que usaba SHT41 y conectores AudioJack4). A partir de ahora, "Completa" = Mini + ECG + bandas de respiración, con MAX30205 (no SHT41) y sin jacks TRRS.
> Todo lo no mencionado aquí es **idéntico a la Mini** — no repetir su documento, solo tomarlo como base y aplicar estos añadidos.

---

## 0. Regla de decisión aplicada para conectores nuevos

Para ECG y bandas de respiración, se sigue el mismo criterio ya usado en la Mini para diferenciar GSR de los sensores I2C: **el tipo de conector depende de si el elemento se pone/quita del cuerpo en cada sesión, no del tipo de señal.**

| Elemento | ¿Se coloca/retira cada sesión? | Conector |
|---|---|---|
| GSR (electrodos) | Sí | Terminal de tornillo |
| Bandas de respiración | Sí | Terminal de tornillo |
| MAX30102, MAX30205 (módulos I2C) | No — se monta una vez | Pads soldados + anclaje |
| AD8232 (módulo ECG) | No — se monta una vez (los electrodos de piel se conectan al propio módulo AD8232, no a nuestra placa) | Pads soldados + anclaje |

---

## 1. Sensores — qué se añade sobre la Mini

| Sensor | Mini | Nueva Completa |
|---|---|---|
| ECG (AD8232) | No | **AÑADIDO** — salida analógica a `AIN0` del ADS1115, ganancia ×1 (±4.096V) |
| Banda respiración torácica | No | **AÑADIDO** — vía buffer MCP6004 canal B → `AIN2`, ganancia ×1 |
| Banda respiración abdominal | No | **AÑADIDO** — vía buffer MCP6004 canal C → `AIN3`, ganancia ×1 |
| GSR, MAX30102, MAX30205 | Presentes | **Sin cambios** respecto a la Mini |

**Confirmado explícitamente**: la Completa usa **MAX30205** para temperatura (no SHT41). Se pierde el canal de humedad ambiente en toda la familia de productos, no solo en la Mini — esto es una decisión de diseño consciente para unificar BOM y firmware entre ambas versiones.

---

## 2. ADS1115 — vuelve a usar los 4 canales

| Canal | Mini | Nueva Completa |
|---|---|---|
| `AIN0` | Sin conectar | ECG, ganancia ×1 |
| `AIN1` | GSR, ganancia ×8 | GSR, ganancia ×8 — sin cambios |
| `AIN2` | Sin conectar | Banda torácica, ganancia ×1 |
| `AIN3` | Sin conectar | Banda abdominal, ganancia ×1 |

**Impacto en firmware — importante**: en la Mini, la ganancia del ADS1115 se fija una única vez en `setup()` (`GAIN_EIGHT`, fijo) porque solo hay un canal activo. En la Completa **hay que recuperar el cambio de ganancia dinámico** entre lecturas, como en la v1.0 original:
- `ads.setGain(GAIN_ONE)` antes de leer `AIN0` (ECG), `AIN2` y `AIN3` (bandas).
- `ads.setGain(GAIN_EIGHT)` antes de la máquina de estados de GSR (`AIN1`).
- Mantener la protección ya existente en el firmware original: **no leer los canales rápidos (ECG/bandas) mientras la máquina de estados de GSR esté ocupando el multiplexor** (`if (okADS && gsrState == GSR_IDLE)`), para evitar colisiones de MUX.

---

## 3. MCP6004 — reactivar canales B y C

| Canal | Mini | Nueva Completa |
|---|---|---|
| A | Buffer V_REF | Buffer V_REF — sin cambios |
| B | No usado (GNDA + feedback) | **Reactivado** — buffer banda torácica |
| C | No usado (GNDA + feedback) | **Reactivado** — buffer banda abdominal |
| D | No usado (GNDA + feedback) | **Sigue sin usar** — mantiene la terminación correcta introducida en la Mini (mejora que se conserva respecto a la v1.0 original) |

---

## 4. Conectores — resumen completo de la nueva versión

| Sensor | Conector |
|---|---|
| GSR | Terminal de tornillo, 2 pines |
| Banda respiración torácica | Terminal de tornillo, 2 pines |
| Banda respiración abdominal | Terminal de tornillo, 2 pines |
| MAX30102 | 4 pads soldados (VCC/GND/SDA/SCL) + anclaje |
| MAX30205 | 4 pads soldados (VCC/GND/SDA/SCL) + anclaje |
| AD8232 (ECG) | 6 pads soldados (3.3V/GND/OUTPUT/LO+/LO-/SDN) + anclaje |

**Nota**: la conexión entre el módulo AD8232 y los electrodos de piel (habitualmente un jack de 3.5mm) es parte del propio módulo AD8232 tal como se vende comercialmente, y queda fuera del alcance de nuestro diseño de PCB — no hay que replicar ese jack en nuestra placa.

---

## 5. Firmware — cambios sobre el `.ino` de la Mini

- **Restaurar variables de ECG**: `e_v`, `he`, `ie`, `re` (igual que v2.5.0 original).
- **Restaurar variables de bandas**: `rt_v`, `ra_v`, `rrt`, `rra`.
- **Restaurar flags**: `enECG`, y equivalentes para bandas si se quiere control individual por Serial (`S_ECG:`, etc., como en `procesarComandos()` de la v1.0 original).
- **Restaurar arquitectura de 5 niveles** (en vez de los 2 niveles de la Mini): 50Hz (ECG/PPG/bandas), 2Hz (GSR/temperatura), y evaluar si se reintroducen los niveles de 0.1Hz (RSA respiratoria) y 30s (telemetría batería/reintentos) documentados en la memoria del proyecto para la v3.2.1.
- **Mantener de la Mini sin cambios**: `leerMAX30205()`, la máquina de estados de GSR, y `apagarSistema()` con su restricción de no usar `delay()` ni `BLEDevice::deinit()`.
- **JSON de salida**: ampliar de nuevo con los campos de ECG y bandas (`e, he, ie, re, rt, rrt, ra, rra`), manteniendo los ya existentes en la Mini (`s, hs, is, rs, g, t, b`). Vigilar el límite de MTU BLE (247 bytes) — con todos los campos activos puede que haga falta el fallback de recorte ya implementado.
- **Nombre BLE**: definir si la Completa usa un nombre distinto (p. ej. `PinaBiosensor_Completa`) para poder diferenciarla de la Mini al emparejar por Bluetooth.

---

## 6. Alimentación, batería y carga

**Sin cambios respecto a la Mini** (ya verificado en el diff anterior): monitor de batería presente sin modificar, carga gestionada íntegramente por el USB-C propio del XIAO, sin circuito de carga adicional, interruptor SW1 sin afectar a la ruta de carga.

---

## 7. BOM — solo lo que se añade sobre la Mini

- AD8232 (módulo ECG)
- 2× sensor de banda respiratoria resistiva (torácica + abdominal)
- 2× terminal de tornillo 2 pines adicionales (bandas) — mismo modelo ya usado para GSR
- 6× pads pasantes + 1 agujero de anclaje adicional (interfaz AD8232 → placa)
- Resistencias/condensadores de protección de entrada si se desea replicar el filtrado de la v1.0 original en las nuevas bandas (revisar si sigue siendo necesario sin el jack TRRS, dado que ahora es terminal de tornillo — recomendable mantenerlo por el mismo motivo que en GSR: un cable sin blindaje capta más ruido)

---

## 8. Resumen ejecutivo

- La nueva "Completa" = Mini + ECG + 2 bandas de respiración, manteniendo el resto de decisiones de la Mini (MAX30205 en vez de SHT41, sin jacks TRRS).
- Los conectores nuevos siguen el mismo criterio ya validado: **terminal de tornillo para lo que se pone/quita del cuerpo cada sesión** (bandas, igual que GSR), **pads soldados para módulos que se montan una vez** (AD8232, igual que MAX30102/MAX30205).
- El firmware debe recuperar el cambio de ganancia dinámico del ADS1115 y la protección anti-colisión de MUX con la máquina de estados de GSR, ambos presentes en la v1.0 original pero innecesarios en la Mini.
- Alimentación, batería y carga: sin ningún cambio en ningún escenario.

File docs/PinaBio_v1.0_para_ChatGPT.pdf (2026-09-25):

Instrucción para ChatGPT: eres un revisor senior de electrónica analógica, KiCad, ESP32 y BLE. No endulces. Trabaja solo con este documento. Responde en español. No pidas Gerbers. Al final responde las 8 preguntas de la sección G. No cambies el nombre BLE ni conviertas esto en un producto médico IEC 60601.

# PinaBio v1.0 (Paca) — diseño fabricado, firmware y críticas

Placa ya pedida a JLCPCB. Pedido SMT026091261919 (5 PCB + 2 PCBA). No se cancela. Nombre BLE exacto: PinaBiosensor. App Android: com.pinabiosensor.mini. Prototipo de biofeedback / laboratorio personal. No diagnostica.

## A. Encargo

1. Validar si lo fabricado + firmware puede funcionar (GSR + PPG/HRV en el móvil + temp + 2 bandas + ECG de juguete).
2. Separar fallos de cobre / firmware / falsos positivos de Gemini y Claude.
3. Qué merece Rev 2 de PCB y qué no.
4. Protocolo BLE binario (además o en lugar de JSON v3) y apaño ECG AD8232 → ADC del XIAO en esta placa.
5. Riesgos USB + piel, sin fingir certificación médica.

No cambiar: ADP150AUJZ-3.3 en este análisis; sleep en D3/GPIO4 (nunca GPIO3); I2C MAX/ADS alimentados desde +3V3 del XIAO (no V_ANALOG) para evitar back-power; HRV lo calcula el teléfono.

## B. Hardware enviado a fabricar

B.1 Qué mide

1. GSR en borne J3 (2 pines).
2. PPG: MAX30102 externo, pads J4, I2C 0x57.
3. Temp: MAX30205 en J5, 0x48.
4. ECG laboratorio: módulo AD8232 (SparkFun/clones), pads J8 6P.
5. Bandas resistivas tórax J6 y abdomen J7.
6. Tensión LiPo 1S (el % lo hace el teléfono).

Sesión con piel: solo BLE. USB-C del XIAO solo programar/cargar con electrodos fuera.

B.2 Mecánica y RF as-built

110 × 70 mm útiles (panel 110 × 80 = riel 5 + placa + riel 5). FR-4 1,6 mm, 2 capas, 1 oz, HASL, vias tented, verde.
Taladros M3 H1–H4.
Zócalo XIAO U1 en (20, 20) mm. USB hacia Y=0 pero no al borde. Cobre GNDD bajo el módulo.
Antena Seeed ESP32-S3: U.FL + cable de la bolsa, no cerámica en USB. Sin cable BLE flojo. Caja plástico; no metal ni LiPo bajo el XIAO.
Layout RF “v1.1” existe y NO es este pedido.

B.3 Alimentación

9/24/26, 9:15 PM | PinaBio v1.0 Paca — ficha para ChatGPT
file:///workspace/docs/PinaBio_v1_revision_chatgpt.html | 1/6
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

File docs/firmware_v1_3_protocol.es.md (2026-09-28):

# Firmware PinaBiosensor 1.3 — protocolo (español)

Especificación para la Paca v1.0 fabricada y el sketch `firmware/PinaBiosensor_Firmware_v1_3/PinaBiosensor_Firmware_v1_3.ino`.

**El formato en el cable es el de firmware 1.2.** El byte de versión sigue siendo **`0x12`**. Un receptor que ya acepta 1.2 debe seguir aceptando `0x12`. No exige `0x13`.
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

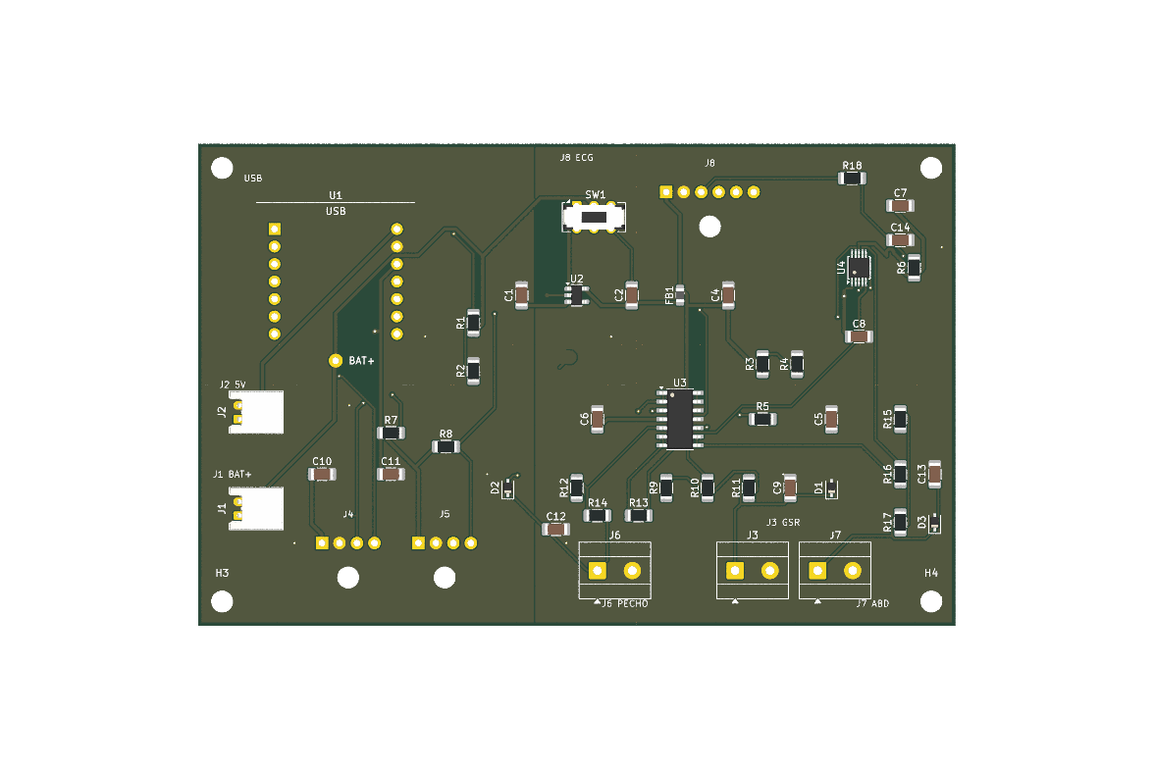
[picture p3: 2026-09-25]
exports/pcb_3d_top.png

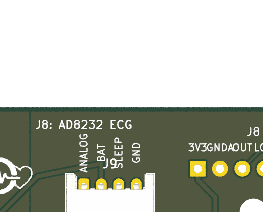
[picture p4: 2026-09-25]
exports/silk_j9_closeup.png

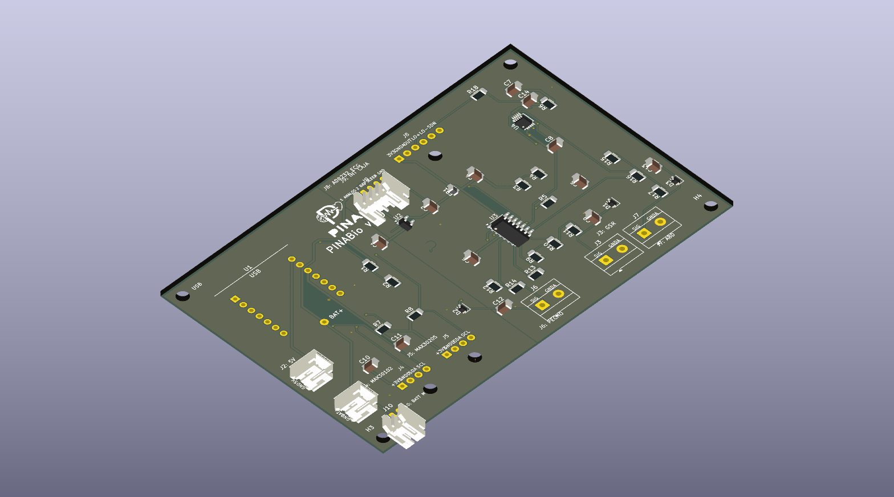
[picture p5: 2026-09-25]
exports/pcb_3d_caja_iso.png

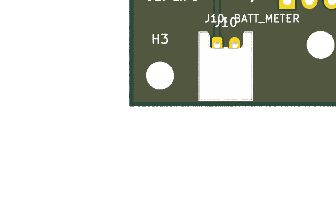
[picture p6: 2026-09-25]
exports/silk_j10_closeup.png

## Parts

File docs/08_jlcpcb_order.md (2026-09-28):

[English](#) | [Español](08_pedido_jlcpcb.md)

# JLCPCB order — PinaBio v1.0 (Paca)

> **Verified archive restored on `main` (2026-09-28).** The three `exports/PinaBio_v1_*` files match the SHA-256 values in `exports/archive_v1.0/SHA256SUMS`, including the original gerber ZIP. Check those hashes before a repeat order; do not substitute `exports/gerbers/` or v1.1 files.

For: **Alejandro**. You do not need KiCad. Do not open or edit the fab files.

Product: **PinaBio v1.0** (nickname **Paca**, after Alejandro’s grandmother). On the phone, Bluetooth is still **`PinaBiosensor`** (do not change it).

A **v1.1** board (XIAO USB at the edge) exists for a **future** order only. For **this** paid order use **`PinaBio_v1_*`**, not `PinaBio_v1.1_*`. See `docs/10_pinabio_v1.1_rf.md`.

This is **not** a medical device. With electrodes or bands on skin: **Bluetooth only**. **Never** PC USB and skin at the same time.

The former `kicad-completa` branch is absent from the current GitHub remote. The verified order files are now directly under `exports/` on `main`.

---

## 0. What you get

One order. The factory makes **5 PCBs** and solders parts on **2** of them.

- **2 assembled boards** (resistors, capacitors, chips, and connectors the factory can place).
- **3 bare boards** (green PCB only). Spares or practice.

This does **not** include the XIAO module, MAX/AD8232 sensors, battery, bands, or the box switch. You buy those (section 7).

---

## 1. The 3 files

You need **exactly 3 files** (names as of September 2026):

| Role | Exact name | Path |
|---|---|---|
| Copper / drills / silk | `PinaBio_v1_gerbers.zip` | `exports/PinaBio_v1_gerbers.zip` |
| Parts list for the factory | `PinaBio_v1_bom_jlc.csv` | `exports/PinaBio_v1_bom_jlc.csv` |
| Where each part sits | `PinaBio_v1_cpl.csv` | `exports/PinaBio_v1_cpl.csv` |

The original notes also used “Completa” names for copies. Use the `PinaBio_v1_*` trio on `main`, whose hashes match the archived manifest; do not mix packages.

**Do not** upload `exports/gerbers/` files named `PinaBiosensor_Mini-...`. That is a **different** (Mini) board.

The original gerber ZIP is now on `main`, alongside its BOM/CPL. The `kicad-completa` branch is no longer needed. Verify all three against `exports/archive_v1.0/SHA256SUMS` before uploading for paid order `SMT026091261919` or a repeat order.

The verified ZIP contains Gerber entries with the historical `PinaBiosensor_Mini-` prefix. Identify this package by the **outer ZIP hash**, not those internal names; the loose `exports/gerbers/` files have not been verified as this paid-order ZIP.

- Do not unzip `PinaBio_v1_gerbers.zip` to “fix” anything. Upload the **whole ZIP**.
- Do not save the CSVs from Excel if it wants to convert numbers or commas.

---

## 2. Sign up at JLCPCB

1. Open **https://jlcpcb.com**.
2. **Sign up** / **Register**, confirm email if asked, then **Log in**.

---

## 3. Upload gerbers and check the viewer

1. **Quote now** (sometimes **Instant Quote**).
2. Upload **`PinaBio_v1_gerbers.zip`**.
3. Wait for the board viewer.

Checklist:

- Size about **110 × 70 mm**. If it shows ~50×30, you uploaded the Mini — cancel.
- If engineering says the Gerber is **110×80**: that is the **panel** with 5 mm rails (5+70+5). Reply that the **finished board is 110×70 mm**. Do not approve an 80 mm tall PCB.
- Silk must show **J9** (box switch, 4 pins) and **J10** (battery meter, 2 pins).
- **No SW1** on the board. The switch is in the **box**, wired to J9.
- Rectangle, 4 corner screw holes.
- Text **PINA** / **PINABio v1.0** (no “Paca” on the PCB).

Then **Next** / **Confirm**.

---

## 4. PCB options

| Field | Set this |
|---|---|
| **PCB Qty** | **5** |
| Layers | **2** |
| PCB Thickness | **1.6 mm** |
| PCB Color | **Green** |
| Surface Finish | **HASL** (LeadFree HASL is fine). ENIG is optional and costs more. |
| Copper Weight | **1 oz** if shown |

No panel. Loose boards, qty **5**. **Do not pay yet.** Assembly is lower on the same page.

---

## 5. Assembly (PCBA): yes, 2 boards

1. **PCB Assembly** → ON.
2. **PCBA Qty**: **2**.
3. Side: **Top side**.
4. Start with **Economic**. If the site blocks through-hole connectors (JST, terminals, socket), switch to **Standard**.
5. **Confirm** / **Next**.

---

## 6. BOM + CPL, matching, DNP, polarity

1. BOM: `PinaBio_v1_bom_jlc.csv`.
2. CPL: `PinaBio_v1_cpl.csv`.
3. **Process BOM&CPL**.

Two BOM lines may need a manual match or **Do not place**:

- **U1** — XIAO **socket** (not the module). Example LCSC **C2932672** (check it is 2.54 mm female 1×7). If unsure, DNP U1 and solder at home.
- **J3, J6, J7** — 2-pin screw terminals, **5.08 mm**. Example **C475082**. Compare the photo to the board. If the body will not fit, DNP and buy separately.

Factory **should** place: resistors, capacitors, ferrite FB1, diodes D1 D2 D3, chips **U2 U3 U4**, connectors **J1 J2 J9 J10**, and U1 / J3 / J6 / J7 if the service allows.

**Do not place:** XIAO module, MAX30102, MAX30205, AD8232, pads **J4 J5 J8**, **SW1** (does not exist), holes **H1–H4**, jumper copper **NT1**.

Polarity in the assembly viewer before pay: **U2 U3 U4** pin 1, diodes D1–D3, JST latches toward the edge as drawn. U2 and U3 CPL rotation is **180°** (KiCad PCB stays 0°) so LCSC pin1 matches the silk triangle; **do not set U3 back to 0°**; **do not rotate U4**. If a part is still 180° wrong, **do not pay** — fix the CPL file, do not eyeball Excel. The cart 3D viewer may ignore CPL rotation until DFM; confirm the Part Placement table, not only the purple body.

Some 1206 resistors (and U2–U4) are **Extended** parts. That surcharge is normal.

---

## 7. Parts you buy yourself

For each board you actually use (start with the 2 assembled ones):

| What | Notes |
|---|---|
| Seeed **XIAO ESP32-S3** | Socket. S3, not RP2040. |
| 2× female 1×7 2.54 mm | Only if factory skipped U1. |
| 5.08 mm 2P terminals | Only if J3/J6/J7 were DNP. |
| **MAX30102** | Pulse; wires to J4. |
| **MAX30205** | Temperature; J5. |
| **AD8232** | Lab ECG; J8. Not a hospital ECG. |
| **1S LiPo with protection** | JST to J1. Pin 1 +, pin 2 GND. |
| Panel **DPDT** + 4 wires | To **J9**. No SW1 on the PCB. |
| Battery meter (optional) | Plug into **J10**. |
| Chest/abdomen stretch bands | Terminals J6 and J7. |
| GSR electrodes | Terminal J3. |
| AD8232 electrodes | On the ECG module, not the main board. |
| M3 screws + box | Four corner holes. |

Phone BLE name: **`PinaBiosensor`**. Board silk: PinaBio v1.0.

---

## 8. Pay, wait, first power-up

Cart: **5** PCBs, **2** assembled, green, 1.6 mm. Ship to your address, pay.

### First power-up (safety)

1. **Nobody** wearing electrodes, bands, or ECG.
2. **PC USB unplugged** until you have inspected the dry board. Then you may program the XIAO over USB **with no skin**.
3. If the XIAO is not fitted: power off, insert it matching silk (USB toward the drawn edge).
4. **No** battery and **no** sensors: look for solder bridges and crooked chips.
5. USB **only** to the XIAO for a few seconds: no burning smell, no instant-hot chip. If it smells: USB out. Do not throw a LiPo in household trash.
6. Box switch wires to **J9** (4 wires). Until then analog power may not match the final design.
7. Battery **only** with protection, on **J1**, correct polarity. **Never** USB and skin together.
8. Skin session: **Bluetooth only**, computer USB **out**.

This order only builds **PinaBio v1.0** hardware. The current firmware is documented separately in `firmware/`.

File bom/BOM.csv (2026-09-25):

PinaBio v1.0 | Ref | Value | Footprint | Qty | LCSC | Notas
Seeed XIAO ESP32-S3 (modulo) | U1 | XIAO_ESP32S3 | Pina:XIAO_ESP32S3_Socket | 1 |  | DNP modulo; zocalo 2x hembra 1x7 2.54mm + pad BAT+; emparejar en web (p.ej. C2932672 x2) o suelda Alejandro
ADP150AUJZ-3.3 | U2 | 3.3V LDO | SOT-23-5 | 1 | C29149 | ADP150AUJZ-3.3-R7 TSOT-23-5; JLC Extended
MCP6004-I/SL | U3 | MCP6004 | SOIC-14 | 1 | C1346056 | SOIC-14; JLC Extended
ADS1115IDGSR | U4 | ADS1115 | VSSOP-10 | 1 | C37593 | ADS1115IDGSR VSSOP-10; JLC Extended
Ferrita 600ohm | FB1 | 600R@100MHz | 0805 | 1 | C113034 | BLM21AJ601SN1D 600ohm@100MHz 0805 Murata
R 47k 1% | R1 R2 R12 R15 | 47k | 1206 | 4 | C25833 | 1206W4F4702T5E UNI-ROYAL 1%; JLC Extended (no hay Basic 1206 47k)
R 56k 0.1% | R3 | 56k | 1206 | 1 | C4257433 | MCA12060D5602BP100 Vishay 0.1%; Extended; stock en web
R 10k 0.1% | R4 | 10k | 1206 | 1 | C2507497 | RNCF1206BTC10K0 Stackpole 0.1%; Extended; stock en web
R 47 1% | R5 | 47 | 1206 | 1 | C17969 | 1206W4F470JT5E UNI-ROYAL; Extended
R 10k 1% | R6 | 10k | 1206 | 1 | C17902 | 1206W4F1002T5E UNI-ROYAL; JLC Basic
R 2.2k 1% | R7 R8 | 2.2k | 1206 | 2 | C17948 | 1206W4F2201T5E UNI-ROYAL; Extended
R 100k 1% | R9 | 100k | 1206 | 1 | C17900 | 1206W4F1003T5E UNI-ROYAL; JLC Basic
R 470 1% | R10 R13 R16 | 470 | 1206 | 3 | C4502 | 1206W4F4700T5E UNI-ROYAL; Extended
R 1k 1% | R11 R14 R17 R18 | 1k | 1206 | 4 | C4410 | 1206W4F1001T5E UNI-ROYAL; JLC Basic
C 1uF | C1 C2 C8 | 1uF | 1206 | 3 | C1848 | CL31B105KBHNNNE 1uF 50V X7R 1206 Samsung; JLC Basic
C 10uF | C4 | 10uF | 1206 | 1 | C13585 | CL31A106KBHNNNE 10uF 50V X5R 1206 Samsung; JLC Basic
C 4.7uF | C5 | 4.7uF | 1206 | 1 | C29823 | 1206B475K500NT 4.7uF 50V X7R 1206 FH; JLC Basic
C 100nF | C6 C7 C9 C10 C11 C12 C13 C14 | 100nF | 1206 | 8 | C24497 | CL31B104KBCNNNC 100nF 50V X7R 1206 Samsung; JLC Basic
TVS 5V SOD-323 | D1 D2 D3 | PESD5V0S1BA | SOD-323 | 3 | C19224 | PESD5V0S1BA SOD-323 bidir (PESD5V0S1UL es DFN1006; no encaja en este footprint)
Net-tie | NT1 | NetTie-2 |  | 1 |  | DNP / cobre; no es componente de fabrica
JST PH 2P | J1 J2 J10 | LiPo / 5V / BATT METER | JST_PH_S2B-PH-K | 3 | C173752 | S2B-PH-K-S(LF)(SN) TH R/A; JLC wave/THT
JST PH 4P | J9 | INT CAJA DPDT | JST_PH_S4B-PH-K | 1 | C157926 | S4B-PH-K-S(LF)(SN) TH R/A; fabrica monta conector NO slide
Borne 2P 5.08 | J3 J6 J7 | GSR / pecho / abdomen | Metz RT01602HBWC 5.08 2P H | 3 |  | emparejar en web: Metz RT01602HBWC; candidato KF128R-5.08-2P C475082 (verificar cuerpo vs footprint)
Pads 4P | J4 J5 | MAX30102 / MAX30205 | Pina:SensorCable_4P_Anchor | 2 |  | DNP fabrica (solo pads)
Pads 6P | J8 | AD8232 | Pina:SensorCable_6P_Anchor | 1 |  | DNP fabrica (solo pads)
M3 | H1-H4 | M3 | MountingHole_3.2mm_M3 | 4 |  | DNP
SW1 (no existe) |  |  |  | 0 |  | No hay slide en placa; DPDT va en panel/caja a J9
Modulo MAX30102 |  |  |  | 1 |  | DNP fabrica
Modulo MAX30205 |  |  |  | 1 |  | DNP fabrica
Modulo AD8232 |  |  |  | 1 |  | DNP fabrica
Banda goma resistiva pecho |  |  |  | 1
Banda goma resistiva abdomen |  |  |  | 1
LiPo 1S con proteccion |  |  |  | 1
Electrodos GSR |  |  |  | 1
Electrodos ECG del AD8232 |  |  |  | 1
NOTA ensamblaje |  |  |  |  |  | Soldar todo SMD (ADS1115, resto), zocalo XIAO, J1 J2 J10, bornes J3 J6 J7, conector J9. NO montar slide SW1. LCSC verificados en jlcpcb.com/lcsc.com 2026-09-12; stock y Basic/Extended cambian — revisar en el carrito.

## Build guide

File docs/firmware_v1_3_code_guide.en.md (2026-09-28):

# Firmware 1.3 code review guide (English)

Source: `firmware/PinaBiosensor_Firmware_v1_3/PinaBiosensor_Firmware_v1_3.ino`. Same hardware map, BLE name, UUIDs and binary layout as 1.2 (`PROTOCOL_VERSION=0x12`). Read [`firmware_v1_2_code_guide.en.md`](firmware_v1_2_code_guide.en.md) for the module table; this file only lists 1.3 changes.

## What 1.3 changes

1. `adsStartAndRead`: `delayMicroseconds(ADS_860_SETTLE_US)` then 50 µs OS polls. No `vTaskDelay(1)` inside the conversion wait.
2. `dropStateGuard` + START / `SET PPG_RATE` / `DEFAULTS` release `stateMutex` during long I²C, then take a new `StateGuard`.
3. `configurePpgHardware(rate, previous, stopped)` + `applyPpgHardwareRateLocked` read back MAX30102 `SPO2_CONFIG` sample-rate bits and `MODE_CONFIG.SHDN`. A failed apply triggers a verified attempt to restore `previous`. `PPG_APPLIED` alone updates `ppgRateCfg`. `PPG_UNVERIFIED` marks PPG unavailable and prevents START/deep sleep until reboot with successful setup; `PPG_UNCHANGED` retains the previous rate.
4. `clearBeatPreview()` used by START, STOP and PPG rate change. STOP no longer leaves `ppgHr`/`ppgRrMs` sticky.
5. `ppgTask` snapshots `ppgRateCfg` under `stateMutex` **before** `i2cMutex` (lock order: never I²C then state). Commands snapshot `previous`, run I²C without `stateMutex`, then publish `ppgRateCfg`, `ppgParked`, `ppgPowerUnverified` and `ppgOk` under a new `StateGuard`. The FIFO clear helper never writes `ppgParked` outside this lock.
6. Autosave calls `saveConfig()` under `StateGuard`.
7. `STATUS` includes `fw=1.3 proto=0x12`. `FIRMWARE_VERSION[]` is `"1.3"`.

## What 1.3 does not change

No VBUS/USB+skin detector. Pin map and I²C addresses unchanged. Sleep/SHDN/CCCD/peek-discard/telemetry seq behaviour from 1.2 remains.

Measured SPS on the PCBA is still the authority for ECG 250 / AUTO_ECG 500.

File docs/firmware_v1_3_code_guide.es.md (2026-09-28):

# Guía de revisión del firmware 1.3 (español)

Fuente: `firmware/PinaBiosensor_Firmware_v1_3/PinaBiosensor_Firmware_v1_3.ino`. Mismo mapa de pines, BLE, UUID y layout binario que 1.2 (`PROTOCOL_VERSION=0x12`). La tabla de módulos está en [`firmware_v1_2_code_guide.es.md`](firmware_v1_2_code_guide.es.md); aquí solo van los cambios 1.3.

## Qué cambia

1. `adsStartAndRead`: espera `ADS_860_SETTLE_US` y sondea OS a 50 µs. Sin `vTaskDelay(1)` en esa espera.
2. `dropStateGuard`: START / `SET PPG_RATE` / `DEFAULTS` sueltan `stateMutex` durante I²C largo.
3. `configurePpgHardware(rate, previous, stopped)` lee la tasa en `SPO2_CONFIG` y SHDN en `MODE_CONFIG`. Si falla, intenta restaurar `previous` y verifica la restauración. Solo `PPG_APPLIED` cambia `ppgRateCfg`. `PPG_UNVERIFIED` deja PPG no disponible y bloquea START/deep sleep hasta reiniciar con configuración correcta; `PPG_UNCHANGED` mantiene la tasa anterior.
4. `clearBeatPreview()` en START, STOP y cambio de tasa PPG.
5. `ppgTask` copia `ppgRateCfg` bajo mutex **antes** de I²C. Los comandos capturan `previous`, hacen I²C sin `stateMutex` y publican `ppgRateCfg`, `ppgParked`, `ppgPowerUnverified` y `ppgOk` con otro `StateGuard`. El helper FIFO no escribe `ppgParked` fuera del mutex.
6. Autosave NVS con `StateGuard`.
7. `STATUS` incluye `fw=1.3 proto=0x12`.

## Qué no cambia

No hay detector USB+piel. Cobre, direcciones I²C y frames 0x12 iguales. Sleep, SHDN, CCCD y peek/discard siguen como en 1.2.

La tasa medida en la PCBA manda sobre el objetivo 250/500.

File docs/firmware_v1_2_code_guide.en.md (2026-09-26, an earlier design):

# Firmware 1.2 code review guide (English)

Source: `firmware/PinaBiosensor_Firmware_v1_2/PinaBiosensor_Firmware_v1_2.ino`. This guide describes the *implemented code*, its ownership rules, failure paths and limitations so a reviewer can check it without relying on prior chat history. The source is one Arduino sketch because the Arduino build expects a matching folder/sketch name. It targets the fabricated Paca v1.0, never a future PCB.

## 1. Fixed hardware and dependencies

Seeed XIAO ESP32-S3; ADS1115 `0x49` AIN0 ECG, AIN1 GSR, AIN2 thorax, AIN3 abdomen; MAX30102 `0x57`; MAX30205 `0x48`. D0/A0/GPIO1 battery divider 47k/47k; D3/GPIO4 active-low sleep; D8/GPIO7 LO+, D9/GPIO8 LO−; D4/GPIO5 I²C. `PIN_*`, `*_ADDR`, BLE name `PinaBiosensor`, and UUID constants should not be edited to match a different board. Wi-Fi is disabled in `setup()`. ADS ALERT is not wired, so the ADS driver polls OS. SparkFun MAX3010x supplies FIFO and beat helper routines; Arduino-ESP32 supplies BLE, FreeRTOS, Preferences and deep sleep.

## 2. Modules, owners and significant variables

| Code section | Key functions | State and meaning | Owner / lock |
|---|---|---|---|
| Hardware/protocol constants | `adsMuxBits`, `adsGainBits`, frame builders | `PROTOCOL_VERSION=0x12`, addresses, pins, acquisition targets, `PACKET_MAGIC` | Compile-time constants |
| Session/configuration | `handleCommand`, `loadConfig`, `saveConfig`, `defaultsConfig` | `runState`, `sessionGeneration`, `sessionStartUs`, `en*`, `stream*`, `tx*`, `*RateCfg`, `gsrVref`, `configDirty` | `stateMutex`; COMMS writes commands, setup initializes |
| ADC scheduling | `pickNextAdcChannel`, `rebuildAdcSchedule`, `adcTask` | `adcSlots[].nextDueUs` soft due time; `lastAdsChan/lastAdsGain` actual prior conversion; `adcScheduleDirty`; `adcSamples[]`, `adcErrors[]` | ADC task alone changes slots; config and commit use `stateMutex` |
| ADS I²C | `adsWriteConfig`, `adsReadReg16`, `adsStartAndRead` | MUX AIN0–3 (`0x4000`+channel shift); ECG/bands PGA ±4.096 V (`0x0200`); GSR ±0.512 V (`0x0800`); DR 860 | Every Wire transaction uses `i2cMutex`, released on every exit |
| PPG acquisition/power | `configurePpg`, `ppgHardware`, `clearPpgFifoForSession`, `ppgTask`, `processPpgBeat` | `ppgRateCfg`, `ppgFifoOverflow`, `ppgSoftwareOverflow`, `ppgPowerErrors`, `ppgHr`, `ppgRrMs`, `lastBeatTsMs` | PPG task owns regular reads/power; setup/commands reconfigure under `i2cMutex`; result commit under `stateMutex` |
| Slow acquisition | `max30205Read`, `slowTask` | `lastTempC`, `lastBattV`, `lastLo`, `tempOk`, `tempI2cErrors`, `telSeq` | SLOW task; I²C under `i2cMutex`, snapshot under `stateMutex` |
| Rings | `ecgPush/Peek/Discard`, `ppgPush/Peek/Discard`, `telPush/Peek/DiscardIfSeq` | `ecgRing`, `ppgRing`, `telRing`, heads/tails, `ecgDrops`, `ppgDrops`, `telDrops` | Each ring's dedicated `portMUX` protects indices/data; no I/O while held |
| BLE/USB | `bleNotify`, `bleText`, `usbWriteFrame`, `send*Frame`, `process*Commands` | `bleConnected`, `usbBinaryMode`, `bleNotifyAttempts`, `bleNotifyRejected`, `framesGenerated`, `framesSubmitted`, `usbFrames`, `usbShortWrites` | COMMS normally sends; `sleepTask` sends final event after COMMS parks; `bleMutex` serializes setValue/notify |
| Sleep | `sleepTask`, `performDeepSleep` | `sleepRequested`, `deepSleeping`, `adcParked`, `ppgParked`, `slowParked`, `commsParked`, `sleepAborts`, `sleepFailureLatch` | `sleepTask` coordinates; all park flags use `stateMutex` |
| Diagnostics | `statusText`, `printDiagnostics` | `measuredAdcSps[]`, `measuredPpgSps`, health flags, ring depths, stack high-water marks | COMMS normally prints; status values are observations, not rate guarantees |

`ESample` and `PSample` contain raw readings and absolute `uint64_t` microseconds. `SlowSample` contains a telemetry snapshot and a sequence assigned **at acquisition**; this makes dropped snapshots visible. `CmdMsg` copies up to 127 command bytes out of the BLE callback so the callback buffer cannot be used after it changes. `StateGuard` is an RAII wrapper: each successful take has a destructor Give; `pickNextAdcChannel` explicitly gives early and clears `held` to avoid a double Give.

### Global variable dictionary

- `ppg` is the SparkFun sensor driver; `prefs` is the NVS handle. `bleServer` and `chJson/chCmd/chEcg/chPpg/chTel/chEvt/chHr` are created once in `setupBle()` and remain valid until BLE deinit.
- `i2cMutex`, `bleMutex`, `stateMutex` define the three serialized resources. `cmdQueue` transfers copied BLE command text to COMMS. `adcTaskHandle/ppgTaskHandle/slowTaskHandle/commsTaskHandle/sleepTaskHandle` support allocation checks and stack diagnostics. `ecgMux/ppgMux/telMux` protect short ring critical sections.
- `bleConnected` is set by BLE callbacks; `sleepRequested`, `deepSleeping`, `sleepAbortPending`, `sleepFailureLatch` are one-way coordination flags. `adcParked/ppgParked/slowParked/commsParked` are acknowledgements protected by `stateMutex`. `ppgPowerUnverified` blocks a false PPG park acknowledgement after failed setup. `sessionGeneration` invalidates old work; `usbBinaryMode` resets false on boot.
- `runState` controls acquisition. `enEcg/enGsr/enThorax/enAbdomen/enPpg/enTemp/enBattery` enable acquisition; `streamEcg/streamPpg/streamTelemetry/streamJson` control output; `txUsb/txBle` gate transports; `usbEcgStream/usbPpgStream` gate raw USB frames; `autoEcgBoost` changes the ECG target calculation.
- `ecgRateCfg/ppgRateCfg/gsrRateCfg/thoraxRateCfg/abdomenRateCfg` are requested SPS, not measured values. `gsrVref` is the calibration voltage used in GSR conversion. `adcSlots[4]` carry due times; `lastAdsChan/lastAdsGain` record the actual prior conversion for mux accounting; `adcScheduleDirty` requests a rebuild.
- `adsOk/ppgOk` record boot detection/configuration, not continuous health. `tempOk` reflects the most recent MAX30205 read. `lastEcgV/lastGsrUs/lastThoraxV/lastAbdomenV/lastTempC/lastBattV/lastLo` are the latest derived readings used for JSON/telemetry.
- `ppgHr/ppgRrMs`, `lastBeatTsMs`, `hrHist[4]`, `hrHistCount` belong to the approximate beat preview. They reset on START and PPG rate change.
- `adcSamples[4]/adcErrors[4]`, `adcConversions`, `adcMuxChanges`, `ppgSamples` count acquisition and failures. `ppgFifoOverflow` is a lower bound from hardware's 5-bit counter; `ppgOverflowPrev` is its prior read; `ppgSoftwareOverflow` estimates SparkFun ring loss; `ppgI2cErrors` covers explicit PPG register failures; `ppgPowerErrors` covers failed SHDN/wake verification; `tempI2cErrors` counts temperature read failures.
- `ecgDrops/ppgDrops` count rejected new ring samples; `telDrops` counts overwritten oldest telemetry; `cmdDrops` counts BLE commands rejected by the full command queue. `ecgPackets/ppgPackets/telPackets/eventPackets` count successfully submitted frame attempts by type.
- `framesGenerated` counts constructed frames; `framesSubmitted` counts frames with at least one local BLE submission or complete USB write; `bleNotifyAttempts` and `bleNotifyRejected` are local API outcomes; `usbFrames` and `usbShortWrites` count complete/short USB frame writes; `sleepAborts` counts failed sleep barriers. None proves phone reception.
- `ecgSeq/ppgSeq/evtSeq` increment on submitted frames; `telSeq` increments on each telemetry acquisition. `sessionStartUs` is a 64-bit clock origin; `lastTelemetryMs/lastDiagMs` pace output; `configDirtySinceMs/configDirty` pace NVS retries; `bootEventPending` lets COMMS emit BOOT as the sole routine sender after task creation.
- `ecgRing/ppgRing/telRing` hold samples; `ecgHead/ecgTail`, `ppgHead/ppgTail`, `telHead/telTail` are circular indices protected by their matching portMUX. Each ring keeps one slot unused to distinguish full from empty.

Important local names: `generation` is a worker's captured session; `active`/`want` are its start-of-work decision; `hwOn` is PPG's verified power state; `maxLen` is the frame limit; `canBle` requires subscription and sufficient MTU; `submitted` means local API/write acceptance; `periodUs` is estimated sample spacing; `parked` combines sleep acknowledgements. None is a hardware delivery guarantee.

## 3. The important statements and invariants

1. `adsRawToVolts()` uses the **same full-scale range** as `adsGainBits()`. For GSR both select ±0.512 V. `calcGsrUs()` rejects invalid/out-of-range voltages rather than reporting a fabricated conductance.
2. `adsStartAndRead()` writes single-shot configuration, polls the OS bit and reads the conversion. The configured 860 SPS is the ADC's maximum data rate, **not** the number of ECG samples this shared scheduler can deliver. `STATUS actual` and periodic `DIAG` must be measured on the real board.
3. `pickNextAdcChannel()` selects the earliest due enabled slot and releases `stateMutex` before waiting or I²C. This is a soft-deadline scheduler. On a late conversion it advances the slot instead of looping indefinitely to catch up.
4. ADC/PPG/SLOW capture `sessionGeneration` before work and compare it under `stateMutex` before publishing. START/STOP and PPG rate changes invalidate prior work. ADC also checks that its channel remains enabled; PPG checks `enPpg` at commit.
5. `START` freezes the MAX30102, clears and verifies its **physical** FIFO pointers, and drains SparkFun's small RAM ring in addition to the firmware rings. On failure it leaves the session stopped. This avoids old samples entering a new time origin.
6. `ppgHardware(false)` uses SparkFun shutdown, then reads MAX30102 MODE_CONFIG register `0x09` and requires SHDN bit 7. On a mutex timeout or failed read it returns false, increments `ppgPowerErrors`, and PPG does not acknowledge parking. Failed initial configuration sets `ppgPowerUnverified`, also preventing sleep from assuming shutdown. Sleep then aborts after 2 s. A register read proves the bit was set, not that supply current is zero.
7. ECG/PPG builders calculate length from **13-byte header + payload + 2-byte CRC**. They peek first; they discard only after a BLE API invocation with CCCD notifications enabled or a full USB write. A BLE notification can still be lost after the call: this code does not claim end-to-end delivery.
8. If BLE MTU cannot hold one sample, `canBle=false` but USB may still send. When both can send, the BLE size caps the shared frame. The firmware does not keep separate per-transport cursors or replay a frame independently to a lagging client.
9. Telemetry is sequenced in `slowTask`, before queuing. `telPeek()` leaves it queued on send failure; `telDiscardIfSeq()` avoids discarding the next snapshot if the producer overwrote the oldest during a send. `telDrops` exposes ring overwrites.
10. `usbBinaryMode` is false at boot and deliberately absent from `saveConfig()`. In BINARY mode text output is suppressed after the final mode acknowledgement; USB commands remain readable. `usbWriteFrame()` counts short writes, and the host must resynchronize on CRC.
11. `saveConfig()` checks `Preferences.begin` and each byte count returned by `put*`; an error returns `ERR SAVE_NVS` and leaves `configDirty` true for retry. NVS stores multiple independent keys, so this is **not an atomic transaction** across power loss.
12. `performDeepSleep()` first stops acquisition and advances the generation, then waits for four parked acknowledgements. PPG's acknowledgement includes a verified shutdown. If any task fails to park within 2 s, sleep is cancelled, previous run state restored, and `ERR SLEEP_NOT_QUIESCENT` reported. The MAX30205 is still physically powered; measure PCBA sleep current.
13. `STATUS frames_submitted` and `ble_notify_calls` represent *local submissions*. Neither is an ACK from the mobile application. Ring drops, FIFO overflow and sequence gaps must also be checked. `stack_hwm` gives the FreeRTOS minimum remaining stack (ESP-IDF units); watch it during bring-up.

## 4. Review boundaries and limitations

There is no hardware-level validation in this source review. ADS 250 SPS ECG/500 boost, PPG 200 SPS, I²C contention, optical behavior, FIFO overflow and sleep current must be measured. SparkFun's `check()` does not return a complete I²C error report, so `ppg_i2c` mainly counts explicit register operations; it is not a complete PPG bus health metric. The 5-bit MAX30102 overflow counter can saturate; `fifo_ovf` is a lower bound. PPG timestamps are estimates. BLE notify has no phone ACK. JSON v4 remains debug-only. No Android v1.2 client is in this repository.

For a first bring-up, disconnect all electrodes and skin contacts before USB. Compile with a pinned Arduino-ESP32 core and SparkFun library, upload, inspect boot probes and `STATUS`, then measure DIAG after two intervals. Test START/STOP, CRC, MTU 23/24/42/247, USB BINARY with BLE MTU 23, NVS error handling where possible, PPG shutdown register and sleep current. Skin-connected operation uses battery and BLE only. This is not a medical device.

## Primary references

- [TI ADS1115 datasheet](https://www.ti.com/lit/ds/symlink/ads1115.pdf): MUX, PGA and conversion mode/rate.
- [Analog Devices MAX30102 datasheet](https://www.analog.com/media/en/technical-documentation/data-sheets/max30102.pdf): FIFO registers 0x04–0x06 and MODE_CONFIG.SHDN at 0x09 bit 7.
- [SparkFun MAX3010x MAX30105.cpp](https://github.com/sparkfun/SparkFun_MAX3010x_Sensor_Library/blob/master/src/MAX30105.cpp): `clearFIFO`, `shutDown`, `wakeUp`, `check` behavior.
- [Espressif Arduino Preferences reference](https://docs.espressif.com/projects/arduino-esp32/en/latest/api/preferences.html): `put*` byte counts and failure returns.

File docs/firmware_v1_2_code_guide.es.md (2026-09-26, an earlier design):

# Guía de revisión del firmware 1.2 (español)

Fuente: `firmware/PinaBiosensor_Firmware_v1_2/PinaBiosensor_Firmware_v1_2.ino`. Esta guía describe el *código implementado*, quién modifica cada dato, los fallos posibles y los límites conocidos. Permite revisarlo sin leer conversaciones anteriores. Es un solo sketch Arduino con nombre igual a su carpeta. Su hardware es la Paca v1.0 ya fabricada; no incluye ninguna placa futura.

## 1. Hardware fijo y dependencias

Seeed XIAO ESP32-S3; ADS1115 `0x49`: AIN0 ECG, AIN1 GSR, AIN2 tórax, AIN3 abdomen; MAX30102 `0x57`; MAX30205 `0x48`. D0/A0/GPIO1 para batería con divisor 47k/47k; D3/GPIO4 sleep activo bajo; D8/GPIO7 LO+, D9/GPIO8 LO−; D4/GPIO5 I²C. Los `PIN_*`, `*_ADDR`, nombre BLE `PinaBiosensor` y UUID corresponden a este cobre. `setup()` apaga Wi-Fi. ALERT de ADS no llega al XIAO: el driver consulta OS. SparkFun MAX3010x aporta FIFO/detector de pulso; Arduino-ESP32 aporta BLE, FreeRTOS, Preferences y deep sleep.

## 2. Módulos, variables y propietarios

| Módulo | Funciones clave | Variables y significado | Propietario / protección |
|---|---|---|---|
| Constantes | `adsMuxBits`, `adsGainBits`, builders | `PROTOCOL_VERSION=0x12`, direcciones, pines, objetivos SPS, `PACKET_MAGIC` | Constantes de compilación |
| Sesión/configuración | `handleCommand`, `loadConfig`, `saveConfig`, `defaultsConfig` | `runState`, `sessionGeneration`, `sessionStartUs`, `en*`, `stream*`, `tx*`, `*RateCfg`, `gsrVref`, `configDirty` | `stateMutex`; COMMS cambia órdenes, setup inicializa |
| Planificación ADC | `pickNextAdcChannel`, `rebuildAdcSchedule`, `adcTask` | `adcSlots[].nextDueUs`: plazo flexible; `lastAdsChan/lastAdsGain`: conversión anterior real; `adcScheduleDirty`; `adcSamples[]`, `adcErrors[]` | Solo ADC cambia slots; configuración/publicación bajo `stateMutex` |
| ADS por I²C | `adsWriteConfig`, `adsReadReg16`, `adsStartAndRead` | MUX AIN0–3 (`0x4000`+desplazamiento); PGA ECG/bandas ±4,096 V (`0x0200`), GSR ±0,512 V (`0x0800`); DR 860 | Cada transacción Wire con `i2cMutex`, liberado en todas las salidas |
| PPG/energía | `configurePpg`, `ppgHardware`, `clearPpgFifoForSession`, `ppgTask`, `processPpgBeat` | `ppgRateCfg`, `ppgFifoOverflow`, `ppgSoftwareOverflow`, `ppgPowerErrors`, `ppgHr`, `ppgRrMs`, `lastBeatTsMs` | PPG hace lecturas/apagado normales; configuración bajo `i2cMutex`; publicación bajo `stateMutex` |
| Sensores lentos | `max30205Read`, `slowTask` | `lastTempC`, `lastBattV`, `lastLo`, `tempOk`, `tempI2cErrors`, `telSeq` | SLOW; I²C con `i2cMutex`, snapshot con `stateMutex` |
| Rings | `ecgPush/Peek/Discard`, `ppgPush/Peek/Discard`, `telPush/Peek/DiscardIfSeq` | `ecgRing`, `ppgRing`, `telRing`, índices y `ecgDrops`, `ppgDrops`, `telDrops` | Un `portMUX` por ring; nunca hacer I/O mientras esté tomado |
| BLE/USB | `bleNotify`, `bleText`, `usbWriteFrame`, `send*Frame`, `process*Commands` | `bleConnected`, `usbBinaryMode`, `bleNotifyAttempts`, `bleNotifyRejected`, `framesGenerated`, `framesSubmitted`, `usbFrames`, `usbShortWrites` | COMMS envía normalmente; SLEEP envía evento final con COMMS aparcado; `bleMutex` protege setValue/notify |
| Sleep | `sleepTask`, `performDeepSleep` | `sleepRequested`, `deepSleeping`, `adcParked`, `ppgParked`, `slowParked`, `commsParked`, `sleepAborts`, `sleepFailureLatch` | SLEEP coordina; todos los flags parked bajo `stateMutex` |
| Diagnóstico | `statusText`, `printDiagnostics` | `measuredAdcSps[]`, `measuredPpgSps`, salud, colas, mínimos de stack | COMMS imprime normalmente; son observaciones, no garantías de SPS |

`ESample` y `PSample` contienen RAW y microsegundos absolutos `uint64_t`. `SlowSample` guarda telemetría y una secuencia asignada **al adquirirla**, de modo que se vean snapshots perdidos. `CmdMsg` copia hasta 127 bytes desde el callback BLE: no conserva un puntero a memoria efímera. `StateGuard` usa RAII: si toma el mutex, su destructor lo libera. `pickNextAdcChannel` lo libera antes de esperar/I²C y pone `held=false` para evitar doble Give.

### Diccionario de variables globales

- `ppg` es el driver SparkFun; `prefs` maneja NVS. `bleServer` y `chJson/chCmd/chEcg/chPpg/chTel/chEvt/chHr` se crean en `setupBle()` y viven hasta deinit BLE.
- `i2cMutex`, `bleMutex`, `stateMutex` definen los tres recursos serializados. `cmdQueue` lleva copias de órdenes BLE a COMMS. `adcTaskHandle/ppgTaskHandle/slowTaskHandle/commsTaskHandle/sleepTaskHandle` permiten comprobar creación y margen de stack. `ecgMux/ppgMux/telMux` protegen secciones cortas de rings.
- `bleConnected` lo cambian callbacks BLE; `sleepRequested`, `deepSleeping`, `sleepAbortPending`, `sleepFailureLatch` son señales de coordinación. `adcParked/ppgParked/slowParked/commsParked` son confirmaciones bajo `stateMutex`. `ppgPowerUnverified` impide confirmar falsamente el reposo PPG tras un fallo de configuración. `sessionGeneration` invalida trabajo viejo; `usbBinaryMode` comienza false en cada arranque.
- `runState` controla adquisición. `enEcg/enGsr/enThorax/enAbdomen/enPpg/enTemp/enBattery` habilitan sensores; `streamEcg/streamPpg/streamTelemetry/streamJson` controlan salida; `txUsb/txBle` habilitan transportes; `usbEcgStream/usbPpgStream` habilitan RAW USB; `autoEcgBoost` cambia el objetivo ECG.
- `ecgRateCfg/ppgRateCfg/gsrRateCfg/thoraxRateCfg/abdomenRateCfg` son SPS solicitados, no medidos. `gsrVref` calibra conversión GSR. `adcSlots[4]` guardan vencimientos; `lastAdsChan/lastAdsGain` recuerdan la conversión anterior real para contar cambios de MUX; `adcScheduleDirty` pide reconstrucción.
- `adsOk/ppgOk` reflejan detección/configuración inicial, no salud continua. `tempOk` refleja última lectura MAX30205. `lastEcgV/lastGsrUs/lastThoraxV/lastAbdomenV/lastTempC/lastBattV/lastLo` son últimas lecturas derivadas usadas por JSON/telemetría.
- `ppgHr/ppgRrMs`, `lastBeatTsMs`, `hrHist[4]`, `hrHistCount` pertenecen a la vista previa aproximada de pulso. Se reinician en START y al cambiar tasa PPG.
- `adcSamples[4]/adcErrors[4]`, `adcConversions`, `adcMuxChanges`, `ppgSamples` cuentan adquisición/fallos. `ppgFifoOverflow` es cota inferior del contador físico de 5 bits; `ppgOverflowPrev` es lectura anterior; `ppgSoftwareOverflow` estima pérdidas del ring SparkFun; `ppgI2cErrors` cubre operaciones explícitas PPG; `ppgPowerErrors` cubre verificación SHDN/wake; `tempI2cErrors` cuenta fallos de temperatura.
- `ecgDrops/ppgDrops` cuentan muestras nuevas rechazadas por rings llenos; `telDrops` cuenta telemetría antigua sobrescrita; `cmdDrops` cuenta órdenes BLE rechazadas por cola llena. `ecgPackets/ppgPackets/telPackets/eventPackets` cuentan frames enviados localmente por tipo.
- `framesGenerated` cuenta frames construidos; `framesSubmitted` cuenta frames con solicitud BLE local o escritura USB completa; `bleNotifyAttempts/bleNotifyRejected` son resultados locales; `usbFrames/usbShortWrites` cuentan escrituras USB completas/cortas; `sleepAborts` cuenta barreras sleep fallidas. Nada demuestra recepción móvil.
- `ecgSeq/ppgSeq/evtSeq` avanzan con frames enviados; `telSeq` avanza con cada telemetría adquirida. `sessionStartUs` es origen de reloj de 64 bits; `lastTelemetryMs/lastDiagMs` marcan intervalos; `configDirtySinceMs/configDirty` marcan reintentos NVS; `bootEventPending` hace que solo COMMS emita BOOT después de crear tareas.
- `ecgRing/ppgRing/telRing` guardan muestras; `ecgHead/ecgTail`, `ppgHead/ppgTail`, `telHead/telTail` son índices circulares con su portMUX. Cada ring reserva una celda para distinguir lleno de vacío.

Variables locales importantes: `generation` es sesión capturada por una tarea; `active`/`want` deciden si inicia trabajo; `hwOn` indica estado PPG verificado; `maxLen` limita frame; `canBle` exige suscripción y MTU suficiente; `submitted` indica solicitud local aceptada; `periodUs` estima separación temporal; `parked` reúne confirmaciones sleep. Ninguna garantiza entrega física al móvil.

## 3. Sentencias e invariantes que deben comprobarse

1. `adsRawToVolts()` usa exactamente el rango configurado por `adsGainBits()`: para GSR ambos son ±0,512 V. `calcGsrUs()` descarta valores inválidos/fuera de rango, en lugar de inventar conductancia.
2. `adsStartAndRead()` escribe configuración single-shot, consulta OS y lee conversión. 860 SPS es la tasa máxima configurada en el ADC, **no** la cantidad garantizada de muestras ECG con cuatro canales. Medir `STATUS actual`/`DIAG` en placa.
3. `pickNextAdcChannel()` elige el canal habilitado cuyo plazo vence antes y suelta `stateMutex` antes de esperar o usar I²C. Es planificación flexible. Si va tarde, avanza el slot para no quedar atrapado recuperando plazos viejos.
4. ADC/PPG/SLOW capturan `sessionGeneration` antes de trabajar y lo comprueban bajo `stateMutex` al publicar. START/STOP y cambio de tasa PPG invalidan trabajo antiguo. ADC comprueba además que el canal siga habilitado; PPG comprueba `enPpg`.
5. `START` detiene MAX30102, limpia y verifica punteros de FIFO **física**, y vacía el pequeño ring RAM de SparkFun además de los rings propios. Si falla, deja sesión parada. Impide que muestras anteriores reciban el nuevo origen temporal.
6. `ppgHardware(false)` llama al apagado SparkFun y lee después MODE_CONFIG `0x09`: exige bit SHDN 7. Si falla mutex/lectura devuelve false y sube `ppgPowerErrors`; PPG no confirma reposo. Si falla la configuración inicial, `ppgPowerUnverified` también impide suponer apagado. Sleep aborta a los 2 s. La lectura demuestra el bit, no corriente nula.
7. Builders ECG/PPG usan **13 bytes de cabecera + payload + 2 CRC**. Hacen peek y solo descartan tras llamada BLE local con CCCD habilitado o escritura USB completa. BLE aún puede perder la notificación después: no hay confirmación extremo a extremo.
8. Si el MTU BLE no permite una muestra, `canBle=false`, pero USB puede enviarla. Si ambos sirven, BLE limita el tamaño del frame común. No hay cursores separados por transporte ni retransmisión independiente a un cliente atrasado.
9. SLOW asigna secuencia de telemetría antes de encolarla. `telPeek()` conserva el snapshot si falla envío; `telDiscardIfSeq()` evita descartar el siguiente si el productor sobrescribió el más antiguo durante el envío. `telDrops` cuenta esas sobreescrituras.
10. `usbBinaryMode` es false al arrancar y no se guarda con `saveConfig()`. En BINARY se suprime texto tras la última confirmación; las órdenes USB siguen entrando. `usbWriteFrame()` cuenta escrituras cortas; el cliente debe resincronizar por CRC.
11. `saveConfig()` comprueba `Preferences.begin` y el número de bytes de cada `put*`; en error devuelve `ERR SAVE_NVS` y deja `configDirty=true` para reintentar. NVS usa varias claves separadas: **no hay transacción atómica** frente a corte de alimentación.
12. `performDeepSleep()` para adquisición y avanza generación; después espera cuatro confirmaciones de reposo. La de PPG incluye SHDN verificado. Si pasan 2 s sin todas, cancela, restaura `runState` y comunica `ERR SLEEP_NOT_QUIESCENT`. MAX30205 permanece alimentado; medir consumo real.
13. `STATUS frames_submitted` y `ble_notify_calls` son *solicitudes locales*, no ACK del móvil. Observar también rings, FIFO y saltos de secuencia. `stack_hwm` muestra el mínimo stack libre de FreeRTOS (unidades ESP-IDF); vigilarlo en el bring-up.

## 4. Límites de esta revisión y pruebas pendientes

Este código no valida por sí solo la placa. Se deben medir ECG 250 SPS/boost 500, PPG 200, contención I²C, respuesta óptica, pérdidas FIFO y corriente en sleep. `check()` de SparkFun no entrega un registro completo de errores I²C: `ppg_i2c` cuenta principalmente las operaciones explícitas, no toda la salud del bus PPG. El contador MAX30102 de overflow tiene 5 bits y puede saturarse: `fifo_ovf` es una cota inferior. Los timestamps PPG son estimaciones. BLE notify no tiene ACK del móvil. JSON v4 es solo depuración. El repositorio no incluye cliente Android V1.2.

Primer bring-up: desconectar electrodos/bandas antes de USB; compilar con versiones fijadas de Arduino-ESP32 y SparkFun; cargar, revisar sondas iniciales y `STATUS`, y medir DIAG tras dos intervalos. Probar START/STOP, CRC, MTU 23/24/42/247, USB BINARY con BLE MTU 23, fallos NVS cuando sea posible, bit SHDN y corriente en sleep. Con piel conectada, usar batería y BLE. No es un dispositivo médico.

## Fuentes primarias

- [Datasheet TI ADS1115](https://www.ti.com/lit/ds/symlink/ads1115.pdf): MUX, PGA y modo/tasa de conversión.
- [Datasheet Analog Devices MAX30102](https://www.analog.com/media/en/technical-documentation/data-sheets/max30102.pdf): registros FIFO 0x04–0x06 y MODE_CONFIG.SHDN en 0x09 bit 7.
- [Código SparkFun MAX3010x MAX30105.cpp](https://github.com/sparkfun/SparkFun_MAX3010x_Sensor_Library/blob/master/src/MAX30105.cpp): `clearFIFO`, `shutDown`, `wakeUp`, `check`.
- [Referencia Espressif Preferences](https://docs.espressif.com/projects/arduino-esp32/en/latest/api/preferences.html): bytes devueltos por `put*` y errores.

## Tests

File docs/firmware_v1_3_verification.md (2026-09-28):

# Firmware 1.3 verification / Verificación del firmware 1.3

## English

**Static checks in this repository review (2026-09-28):** the V1.3 sketch has balanced C++ delimiters in a lexer that skips comments and strings; the pin/address constants, BLE name, Wi-Fi-off call, ADS GSR PGA bits, CRC-16/CCITT-FALSE vectors and frame/MTU arithmetic remain consistent with V1.2. All new explicit I²C mutex takes have a matching give on the acquired path. V1.2 source remains in the tree. `git diff --check` passes. These checks do **not** compile the sketch.

**MAX30102 rate readback:** the code reads register `0x0A`, sample-rate bits 4:2, and register `0x09`, SHDN bit 7, after both an apply and a rollback. The mapping for 100/200/400 SPS is 1/2/3. This mapping was checked against the [MAX30102 datasheet](https://www.analog.com/media/en/technical-documentation/data-sheets/MAX30102.pdf) and [SparkFun library source](https://github.com/sparkfun/SparkFun_MAX3010x_Sensor_Library/blob/master/src/MAX30105.cpp). A failed readback leaves the result unverified; it is never counted as a successful rollback.

**Still required before use:** compile with a pinned Arduino-ESP32 core, Seeed XIAO ESP32-S3 board definition and SparkFun MAX3010x library. On the fabricated PCBA, inject or observe failed rate writes/readbacks, verify STOP → `SET PPG_RATE` → START, check status and measured PPG SPS, test a failed rollback and the resulting START/sleep refusal, exercise START concurrently with a sleep request, measure ECG SPS after the ADS polling change, and check power consumption. No build, flash or PCBA test was performed in this workspace.

**Fabrication archive:** the current GitHub remote contains only `main`. The original ZIP was recovered from a local archive, copied byte-for-byte to `exports/PinaBio_v1_gerbers.zip`, and its SHA-256 `80ad8ffbf5c0c934477c3629876153e2ca1a08734c8c796fbc24ed5f0dff62f7` matches `exports/archive_v1.0/SHA256SUMS`. The committed BOM/CPL bytes match that same manifest. This review did not regenerate gerbers or establish that the loose `exports/gerbers/` match the paid order.

## Español

**Comprobaciones estáticas de esta revisión (28-09-2026):** delimitadores C++ equilibrados con analizador que ignora comentarios y cadenas; constantes de pines/direcciones, nombre BLE, Wi-Fi apagado, bits PGA GSR, vectores CRC-16/CCITT-FALSE y aritmética frame/MTU coherentes con V1.2. Cada nueva toma explícita del mutex I²C tiene su liberación cuando se adquiere. El código V1.2 sigue en el árbol. `git diff --check` pasa. Estas pruebas **no** compilan el sketch.

**Lectura de tasa MAX30102:** se leen el registro `0x0A`, bits 4:2 de tasa, y `0x09`, bit SHDN 7, tanto después de aplicar como al revertir. La correspondencia 100/200/400 SPS es 1/2/3, contrastada con el [datasheet MAX30102](https://www.analog.com/media/en/technical-documentation/data-sheets/MAX30102.pdf) y el [código SparkFun](https://github.com/sparkfun/SparkFun_MAX3010x_Sensor_Library/blob/master/src/MAX30105.cpp). Si falla la lectura, la reversión no se considera verificada.

**Pendiente antes del uso:** compilar con versiones fijadas de Arduino-ESP32, placa Seeed XIAO ESP32-S3 y librería SparkFun MAX3010x. En la PCBA fabricada, provocar u observar fallos de escritura/lectura de tasa, probar STOP → `SET PPG_RATE` → START, comprobar STATUS y SPS PPG medidos, verificar que un rollback fallido bloquea START/sleep, ensayar START junto con una solicitud sleep, medir SPS ECG tras el cambio de sondeo ADS y consumo. Aquí no se compiló ni flasheó ni se probó la PCBA.

**Archivo de fabricación:** el remoto GitHub actual solo tiene `main`. Se recuperó el ZIP original de un archivo local y se copió sin modificar a `exports/PinaBio_v1_gerbers.zip`. Su SHA-256 `80ad8ffbf5c0c934477c3629876153e2ca1a08734c8c796fbc24ed5f0dff62f7` coincide con `exports/archive_v1.0/SHA256SUMS`, igual que los bytes BOM/CPL guardados en Git. Esta revisión no regeneró los gerbers ni demostró que los sueltos de `exports/gerbers/` coincidan con el pedido pagado.

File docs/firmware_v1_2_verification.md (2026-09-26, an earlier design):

# Firmware 1.2 verification record / Registro de verificación 1.2

## English

**Scope:** static review of the new sketch and documentation for fabricated Paca v1.0. This record does not claim a successful Arduino compile, flash, BLE reception test or PCBA measurement. No compatible Arduino IDE/CLI, ESP32 board package or physical Paca was present in this workspace.

**Checks completed:**

1. Source delimiters checked with a lightweight lexer that ignores C++ comments and strings; no unmatched parentheses/braces/brackets. This is weaker than compilation.
2. CRC-16/CCITT-FALSE independent vectors: `00` → `0xE1F0`; `123456789` → `0x29B1`. The source initializes `0xFFFF`, uses polynomial `0x1021`, and writes the result little-endian after computing through the payload.
3. ATT/MTU arithmetic checked for MTU 23/24/42/247: maximum uncapped ECG samples 2/3/12/114; PPG 0/1/4/38; telemetry 39-byte frame fits at 42 and 247. The source caps ECG at 80, PPG at 30. With BLE MTU 23 and USB BINARY active, PPG now uses USB capacity. Bluedroid CCCD subscription is checked before a BLE submission is considered usable.
4. Every explicit `xSemaphoreTake` path was reviewed for a matching `xSemaphoreGive`; unsuccessful takes return without giving. `StateGuard` releases in its destructor, except for the deliberate early release in `pickNextAdcChannel` where `held=false` prevents a double Give. New PPG FIFO/power helpers each release I²C on the acquired path.
5. Sleep state transitions were reviewed: workers advertise parked only after leaving acquisition; PPG verifies SHDN; COMMS uses cooperative parking; timeout restores prior run state and avoids deep sleep. The remaining effect of an unsuccessful shutdown is a reported sleep abort.
6. Source, root READMEs and hardware cross-references point to firmware 1.2. The old sketch/protocol/changelog are absent from the current tree; historical versions remain recoverable through Git. `git diff --check` passed.
7. MAX30102 register use was cross-checked against the Analog Devices datasheet and SparkFun source: FIFO pointer/counter registers `0x04..0x06`, MODE_CONFIG `0x09`, SHDN bit 7, `clearFIFO()` writes three zeroes, `shutDown()`/`wakeUp()` change SHDN. Preferences byte counts were checked against Espressif documentation.

**Not demonstrated yet:** compile against a pinned Arduino-ESP32 and SparkFun release; actual stack margins, task deadlines, ADS 250/500 SPS, PPG FIFO behavior, BLE delivery at negotiated MTUs, USB short-write recovery and power consumption. `notify()` has no application ACK; all counters named submissions/calls must be treated accordingly. A real build is the next hard gate before a laboratory flash.

**PCBA bring-up checklist (without skin contacts on USB):** boot probe messages for ADS `0x49`, MAX30102 `0x57`, MAX30205 `0x48`; `STATUS` health `1/1/1` and nonzero `stack_hwm`; `STOP` → `START` → `STATUS`; two DIAG intervals and sustained SPS/drops; BLE MTU 23/24/42/247 with CRC/version/sequence checking; USB BINARY PPG while BLE remains at MTU 23; repeated START/STOP and FIFO counter; SLEEP command and GPIO4 entry/wake; verify MAX30102 MODE_CONFIG.SHDN and PCBA sleep current. If any of these fail, do not treat V1.2 as session-ready.

## Español

**Alcance:** segunda revisión estática del sketch y documentación para Paca v1.0 fabricada. No demuestra compilación Arduino, flasheo, recepción BLE ni medidas de la PCBA. Este espacio no tenía Arduino IDE/CLI compatible, paquete ESP32 ni Paca física.

**Comprobaciones realizadas:**

1. Delimitadores del C++ comprobados con analizador ligero que ignora comentarios y cadenas: paréntesis/llaves/corchetes equilibrados. Es una prueba más débil que compilar.
2. Vectores CRC-16/CCITT-FALSE independientes: `00` → `0xE1F0`; `123456789` → `0x29B1`. El código inicia `0xFFFF`, usa `0x1021` y transmite little-endian tras cubrir el payload.
3. Aritmética ATT/MTU para 23/24/42/247: ECG sin límite interno 2/3/12/114; PPG 0/1/4/38; telemetría 39 bytes cabe desde 42. El sketch limita ECG a 80 y PPG a 30. Con MTU BLE 23 y USB BINARY, PPG usa capacidad USB. Se comprueba suscripción CCCD Bluedroid antes de considerar BLE utilizable.
4. Revisadas las rutas explícitas `xSemaphoreTake`/`xSemaphoreGive`; si falla Take se vuelve sin Give. `StateGuard` libera en destructor, salvo liberación anticipada deliberada en `pickNextAdcChannel` con `held=false`. Los nuevos helpers PPG liberan I²C tras tomarlo.
5. Revisados estados sleep: tareas confirman reposo fuera de adquisición; PPG comprueba SHDN; COMMS se aparca sin carrera suspend/resume; timeout restaura estado anterior y evita deep sleep. Si falla apagado PPG se informa abortando sleep.
6. Sketch, README y referencias de hardware apuntan a V1.2. Sketch/protocolo/changelog V1.1 ya no están en árbol actual; Git conserva historial. `git diff --check` pasó.
7. Registros MAX30102 contrastados con datasheet Analog Devices y código SparkFun: FIFO `0x04..0x06`, MODE_CONFIG `0x09`, SHDN bit 7; `clearFIFO()` escribe tres ceros, `shutDown()`/`wakeUp()` modifican SHDN. Bytes devueltos por Preferences contrastados con Espressif.

**Aún sin demostrar:** compilación con versiones fijadas Arduino-ESP32/SparkFun; margen real de stack, plazos, ADS 250/500 SPS, FIFO PPG, entrega BLE con MTU negociado, recuperación ante escritura USB corta y consumo. `notify()` no tiene ACK de aplicación. La compilación real es la siguiente puerta obligatoria antes de flashear en laboratorio.

**Bring-up PCBA (sin contacto corporal durante USB):** mensajes de ADS `0x49`, MAX30102 `0x57`, MAX30205 `0x48`; `STATUS` health `1/1/1` y `stack_hwm` distinto de cero; `STOP` → `START` → `STATUS`; dos intervalos DIAG y SPS/drops sostenidos; BLE MTU 23/24/42/247 con CRC/versión/secuencia; PPG USB BINARY con BLE en MTU 23; START/STOP repetidos y contador FIFO; SLEEP por comando/GPIO4, entrada/wake; comprobar SHDN del MAX30102 y corriente de sleep. Si algo falla, no considerar V1.2 lista para sesiones.

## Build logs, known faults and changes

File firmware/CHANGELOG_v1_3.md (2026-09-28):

# Firmware 1.3 changelog / Registro de cambios 1.3

Target / Destino: fabricated PinaBio Paca v1.0. Firmware 1.2 remains in `firmware/PinaBiosensor_Firmware_v1_2/`. Binary layout is unchanged: **PROTOCOL_VERSION stays 0x12**. Hosts that already accept 1.2 frames do not need a new parser.

## English

1. **ADS poll:** `adsStartAndRead` waits ~1.16 ms (860 SPS conversion) then polls OS with 50 µs delays. It no longer uses `vTaskDelay(1)` on every poll, which could keep ECG well below the 250 SPS target.
2. **STOP heart-rate leftover:** STOP (and a shared `clearBeatPreview`) zeros IR beat preview so HRS/telemetry do not keep the last pulse after the session ends.
3. **PPG rate rollback:** `configurePpgHardware` reads back SHDN and the MAX30102 sample-rate bits after both an apply and any attempted restoration. Only a verified apply changes `ppgRateCfg`. If both operations fail, PPG is unavailable and START/deep sleep are blocked until reboot with successful setup.
4. **START / PPG I²C without `stateMutex`:** START, `SET PPG_RATE` and `DEFAULTS` drop `stateMutex` around long I²C. Shared configuration and park flags are committed only after retaking the mutex. `ppgTask` copies `ppgRateCfg` under the mutex *before* taking I²C (never hold both).
5. **NVS autosave** takes `stateMutex` so it does not race command writes.
6. **STATUS** prints `fw=1.3` and `proto=0x12`.
7. **Not included:** no software USB+skin interlock. This PCB has no VBUS GPIO; CDC “connected” is not 5 V. Charge/flash with electrodes off. Power-bank charging is a user procedure, not a detector.

**Verification:** try a real Arduino-ESP32 compile in this workspace when the core is available. No flash or PCBA measurement is claimed here.

## Español

1. **Sondeo ADS:** espera ~1,16 ms y consulta OS con 50 µs. Ya no usa `vTaskDelay(1)` en cada poll.
2. **STOP:** pone a cero la vista previa de pulso IR.
3. **Tasa PPG:** se leen de vuelta SHDN y los bits de tasa del MAX30102. También se verifica cualquier intento de restaurar la tasa anterior. Si fallan ambas operaciones, PPG queda no disponible y START/deep sleep se bloquean hasta reiniciar con configuración correcta.
4. **START / I²C PPG** sueltan `stateMutex` durante I²C largo, pero publican configuración y reposo solo al recuperarlo. PPG copia la tasa bajo mutex *antes* de tomar I²C.
5. **Autosave NVS** bajo `stateMutex`.
6. **STATUS** incluye `fw=1.3 proto=0x12`.
7. **No hay** interlock USB+piel por software: no hay GPIO de VBUS.

## Repository correction / Corrección del repositorio (2026-09-28)

The old `kicad-completa` branch is absent, but the exact v1.0 gerber ZIP was recovered from a local archive and restored to `main`. It and the committed BOM/CPL bytes match `exports/archive_v1.0/SHA256SUMS`; `.gitattributes` prevents line-ending conversion of those three files. Root READMEs and JLCPCB guides now point to `main`. The V1.2 hardware review is labelled historical; V1.3 is current. / La rama antigua no existe, pero el ZIP exacto v1.0 se recuperó de un archivo local y se restauró en `main`. Él y los bytes BOM/CPL guardados en Git coinciden con `exports/archive_v1.0/SHA256SUMS`; `.gitattributes` evita cambiar finales de línea. README y guías JLCPCB apuntan a `main`. V1.2 queda como revisión histórica; V1.3 es vigente.

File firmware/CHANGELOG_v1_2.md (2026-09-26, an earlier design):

# Firmware 1.2 changelog / Registro de cambios 1.2

Target / Destino: fabricated PinaBio Paca v1.0 with XIAO ESP32-S3. The BLE name, proprietary UUIDs, pin map, sensors and Wi-Fi-off behavior are unchanged. Binary format stays the same but the protocol version byte is **0x12**, so receivers must explicitly accept 1.2.

## English

1. **PPG USB versus small BLE MTU:** `sendPpgFrame` (and ECG) now checks whether BLE can hold at least one sample. If not, USB binary still uses its own size limit. With both usable, BLE determines the common frame length. This fixes the V1.1 case where BLE MTU 23 blocked USB PPG.
2. **Honest transport accounting:** renamed `framesAccepted` to `framesSubmitted`; added `usbShortWrites` and a CCCD subscription check before BLE can consume a ring. BLE `notify()` gives no phone acknowledgement, so `ble_notify_calls` means a local invocation only. The shared ring still cannot guarantee delivery to two independent consumers.
3. **PPG power and sleep:** `ppgHardware` returns success only after reading MAX30102 MODE_CONFIG.SHDN. PPG retries failed shutdown and does not acknowledge parking. Sleep waits for ADC, PPG, SLOW and COMMS, aborts after 2 s on failure, restores the previous run state and reports an error. COMMS parks cooperatively, avoiding a resume-before-suspend race.
4. **Session isolation:** START now clears and verifies the *hardware* PPG FIFO before opening a new session. It stops with an explicit error if this fails. ADC/PPG also check that the channel is still enabled when committing work. PPG rate changes invalidate in-flight batches, clear its ring and reset beat history.
5. **Telemetry loss visibility:** telemetry is sequenced at acquisition; failed sends leave the snapshot queued. A ring overwrite increments `telDrops`; conditional discard avoids consuming the next snapshot if an overwrite happens during output. Sequence gaps expose missing snapshots.
6. **Persistence and resource failures:** SAVE checks Preferences open and every byte count; NVS failures return `ERR SAVE_NVS` and retain dirty state. Setup checks synchronization/task allocations. STATUS exposes sensor health, PPG power errors, sleep aborts, short USB writes and FreeRTOS stack high-water marks.
7. **Core compatibility:** the BLE write callback uses the return type of `getValue()` via `auto`, then copies command bytes into a queue. This handles the String/std::string return difference across Arduino-ESP32 generations; full build compatibility still needs a real compile.
8. **Review documentation:** English and Spanish protocol and code guides explain hardware, modules, variables, lock ownership, important statements, wire format and known limits. V1.1 source and protocol are removed from the current tree; history remains in Git.
9. **MUX diagnostic:** `adcMuxChanges` now compares each conversion against the actual previous ADS channel/gain. The old per-slot comparison could stay at zero even while switching channels.

## Español

1. **PPG USB con MTU BLE pequeño:** `sendPpgFrame` y ECG comprueban si BLE admite una muestra. Si no, USB binario conserva su límite de tamaño. Si ambos sirven, BLE limita el frame común. Se corrige el bloqueo PPG USB con MTU BLE 23 de V1.1.
2. **Contadores honestos:** `framesAccepted` pasa a `framesSubmitted`; se añade `usbShortWrites` y se comprueba suscripción CCCD antes de consumir por BLE. BLE `notify()` no confirma recepción móvil: `ble_notify_calls` es solo llamada local. Un ring común no garantiza entrega independiente a dos clientes.
3. **Energía PPG y sleep:** `ppgHardware` devuelve éxito solo tras leer MODE_CONFIG.SHDN del MAX30102. Si falla el apagado PPG reintenta y no confirma reposo. Sleep espera ADC, PPG, SLOW y COMMS; a los 2 s cancela, restaura estado y comunica error. COMMS se aparca cooperativamente para evitar carrera suspend/resume.
4. **Aislamiento de sesiones:** START limpia y verifica la FIFO *física* PPG antes de abrir sesión. En fallo deja adquisición parada. ADC/PPG comprueban habilitación al publicar. Cambiar tasa PPG invalida lotes en curso, vacía ring y reinicia historia de latidos.
5. **Pérdidas de telemetría visibles:** se asigna secuencia al adquirir; un fallo de envío mantiene snapshot en cola. Sobrewrite suma `telDrops`; descarte condicional evita quitar el siguiente snapshot si hubo sobrewrite durante envío. Los saltos de secuencia muestran snapshots faltantes.
6. **Fallos NVS y recursos:** SAVE comprueba apertura y cada escritura; devuelve `ERR SAVE_NVS` y deja configuración pendiente. Setup comprueba creación de mutex/cola/tareas. STATUS muestra salud, errores de apagado PPG, abortos sleep, escrituras USB cortas y margen mínimo de stack.
7. **Compatibilidad del core:** callback BLE deduce con `auto` el retorno de `getValue()` y copia el comando a cola. Resuelve la diferencia String/std::string; la compatibilidad completa exige compilación real.
8. **Documentación:** protocolo y guía de código en inglés/español explican hardware, módulos, variables, mutex, sentencias clave, formato y límites. Se elimina V1.1 del árbol vigente; Git conserva historial.
9. **Diagnóstico MUX:** `adcMuxChanges` compara con el canal/ganancia de la conversión ADS anterior real. La comparación por slot podía quedarse en cero pese a cambiar de canal.

**Verification / Verificación:** static review only in this workspace. No Arduino compilation, flash or physical PCBA measurements were performed here. / Solo revisión estática en este espacio. Aquí no se compiló, flasheó ni midió la PCBA.

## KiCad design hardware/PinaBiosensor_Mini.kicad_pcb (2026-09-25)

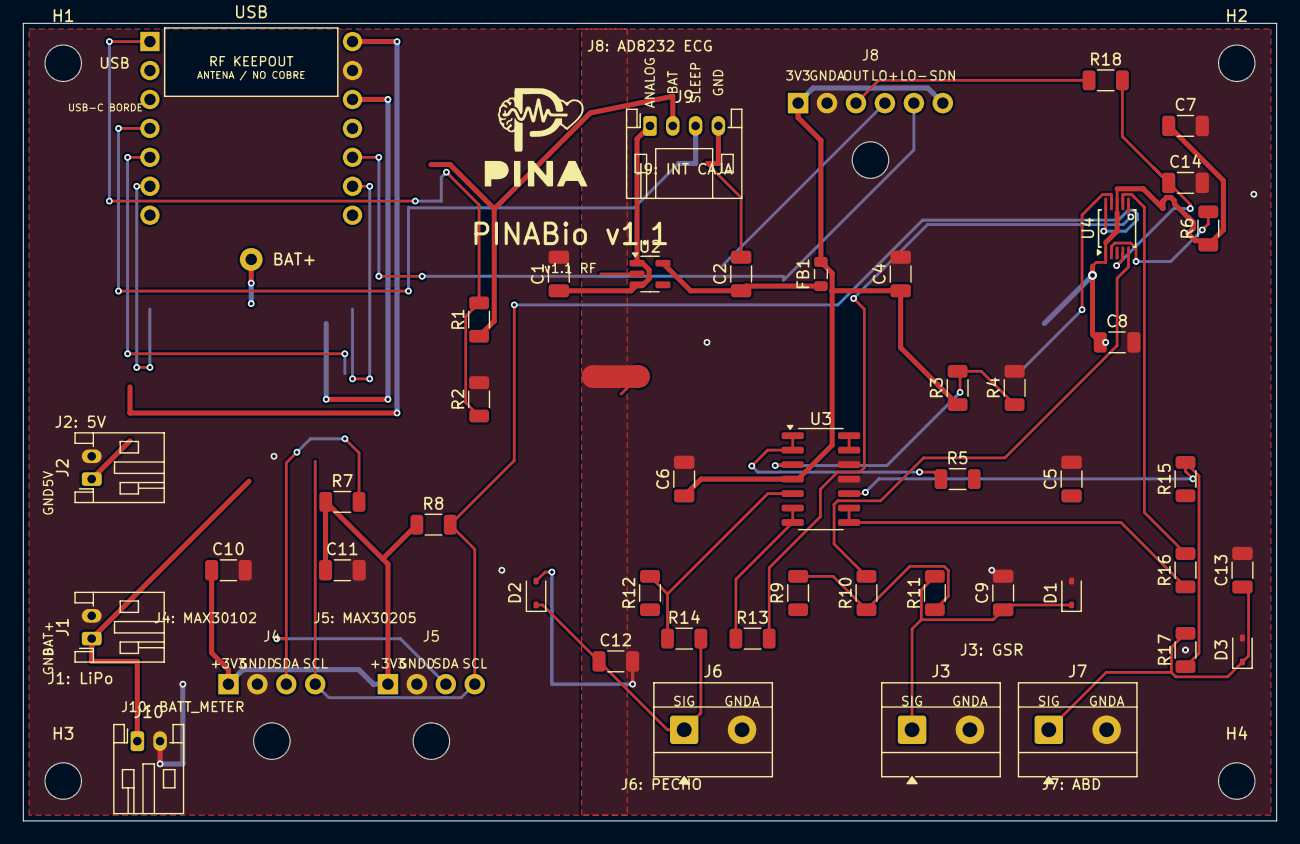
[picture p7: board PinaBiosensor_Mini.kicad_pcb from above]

Board: 2 copper layers, 110.0 x 70.0 mm, 55 parts (0 on the bottom side), 31 nets.

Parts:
C1, C2, C8: 1uF; C_1206_3216Metric
C4: 10uF; C_1206_3216Metric
C5: 4.7uF; C_1206_3216Metric
C6, C7, C9, C10, C11, C12, C13, C14: 100nF; C_1206_3216Metric
D1, D2, D3: PESD5V0S1UL; D_SOD-323
FB1: 600R@100MHz; L_0805_2012Metric
H1, H2, H3, H4: M3; MountingHole_3.2mm_M3
J1: LiPo_JST-PH; JST_PH_S2B-PH-K_1x02_P2.00mm_Horizontal
J2: 5V_CHARGE; JST_PH_S2B-PH-K_1x02_P2.00mm_Horizontal
J3: GSR; TerminalBlock_MetzConnect_Type101_RT01602HBWC_1x02_P5.08mm_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
J4: MAX30102; SensorCable_4P_Anchor
J5: MAX30205; SensorCable_4P_Anchor
J6: RESP_THORAX; TerminalBlock_MetzConnect_Type101_RT01602HBWC_1x02_P5.08mm_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
J7: RESP_ABDOMEN; TerminalBlock_MetzConnect_Type101_RT01602HBWC_1x02_P5.08mm_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
J8: AD8232; SensorCable_6P_Anchor
J9: INT_CAJA_DPDT; JST_PH_S4B-PH-K_1x04_P2.00mm_Horizontal
J10: BATT_METER; JST_PH_S2B-PH-K_1x02_P2.00mm_Horizontal
LOGO: PINA_Logo
NT1: NetTie_2; NetTie-2_SMD_Pad2.0mm
R1, R2, R12, R15: 47k 1%; R_1206_3216Metric
R3: 56k 0.1%; R_1206_3216Metric
R4: 10k 0.1%; R_1206_3216Metric
R5: 47; R_1206_3216Metric
R6: 10k; R_1206_3216Metric
R7, R8: 2.2k; R_1206_3216Metric
R9: 100k; R_1206_3216Metric
R10, R13, R16: 470; R_1206_3216Metric
R11, R14, R17, R18: 1k; R_1206_3216Metric
U1: XIAO_ESP32S3; XIAO_ESP32S3_Socket
U2: ADP150AUJZ-3.3; SOT-23-5
U3: MCP6004; SOIC-14_3.9x8.7mm_P1.27mm
U4: ADS1115IDGS; TSSOP-10_3x3mm_P0.5mm

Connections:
+3V3: C7.1, C8.1, C10.1, C11.1, J4.1, J5.1, R6.1, R7.1, R8.1, U1.12, U4.1, U4.8
+5V: J2.1, U1.14
AB_AIN: R16.2, U4.7
AB_ELEC: C13.1, D3.1, J7.1, R17.2
AB_MID: R15.2, R17.1, U3.10
ADS_ALERT: R6.2, U4.2
ECG_AIN: C14.1, R18.2, U4.4
ECG_LON: J8.5, U1.10
ECG_LOP: J8.4, U1.9
ECG_OUT: J8.3, R18.1
GNDA: C4.2, C5.2, C6.2, C7.2, C8.2, C9.2, C12.2, C13.2, C14.2, D1.2, D2.2, D3.2, J3.2, J6.2, J7.2, J8.2, NT1.1, R4.2, U3.11, U3.12, U4.3
GNDD: C1.2, C2.2, C10.2, C11.2, J1.2, J2.2, J4.2, J5.2, J9.4, J10.2, NT1.2, R2.2, U1.13, U2.2
GSR_AIN: R10.2, U4.5
GSR_ELEC: C9.1, D1.1, J3.1, R11.2
GSR_MID: R9.2, R10.1, R11.1
LDO_OUT: C2.1, FB1.1, U2.5
LDO_VIN: C1.1, J9.1, U2.1, U2.3
unnamed: R5.1, U3.1, U3.2
unnamed: R13.1, U3.6, U3.7
unnamed: R16.1, U3.8, U3.9
unnamed: U3.13, U3.14
SCL: J4.4, J5.4, R8.2, U1.6, U4.10
SDA: J4.3, J5.3, R7.2, U1.5, U4.9
SLEEP_N: J9.3, U1.4
TH_AIN: R13.2, U4.6
TH_ELEC: C12.1, D2.1, J6.1, R14.2
TH_MID: R12.2, R14.1, U3.5
VBAT_DIV: R1.2, R2.1, U1.1
VREF_DIV: R3.2, R4.1, U3.3
V_ANALOG: C4.1, C6.1, FB1.2, J8.1, J8.6, R3.1, U3.4
V_BATT: J1.1, J9.2, J10.1, R1.1, U1.15

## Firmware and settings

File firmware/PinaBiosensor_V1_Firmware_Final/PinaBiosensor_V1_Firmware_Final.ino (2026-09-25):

/*
 * PinaBiosensor V1 - engineered firmware
 * Target: Seeed Studio XIAO ESP32-S3
 *
 * Hardware fixed by fabricated V1 PCB:
 *   ADS1115 0x49  AIN0=ECG, AIN1=GSR, AIN2=thorax, AIN3=abdomen
 *   MAX30102 0x57 external module, RAW RED + IR
 *   MAX30205 0x48 temperature
 *   Battery D0/A0/GPIO1, 47k/47k divider on PCB
 *   Sleep D3/GPIO4 active LOW
 *   AD8232 leads-off D8/GPIO7 and D9/GPIO8
 *   I2C SDA D4/GPIO5, SCL D5/GPIO6
 *
 * Communication:
 *   BLE name remains exactly: PinaBiosensor
 *   Custom service UUID is kept for compatibility.
 *   ECG RAW and PPG RAW use independent binary notify characteristics.
 *   Telemetry is separate. Commands are bidirectional over BLE and USB.
 *   Wi-Fi is intentionally not used.
 *
 * IMPORTANT:
 *   This firmware is a testable engineering baseline, not a medical device.
 *   Target sample rates are configurable goals. STATUS/DIAG reports measured
 *   rates so the real PCBA can be characterized without changing code.
 */

#include <Arduino.h>
#include <Wire.h>
#include <MAX30105.h>
#include "heartRate.h"
#include <BLEDevice.h>
#include <BLEServer.h>
#include <BLEUtils.h>
#include <BLE2902.h>
#include <Preferences.h>
#include "driver/rtc_io.h"
#include "esp_sleep.h"
#include "esp_timer.h"
#include <math.h>
#include <ctype.h>
#include <string.h>
#include <strings.h>
#include <string>

// ----------------------------------------------------------------------
// Hardware
// ----------------------------------------------------------------------
static constexpr uint8_t ADS_ADDR  = 0x49;
static constexpr uint8_t PPG_ADDR  = 0x57;
static constexpr uint8_t TEMP_ADDR = 0x48;

static constexpr int PIN_VBAT  = A0;  // D0 / GPIO1
static constexpr int PIN_SLEEP = D3;  // D3 / GPIO4
static constexpr int PIN_SDA   = D4;  // D4 / GPIO5
static constexpr int PIN_SCL   = D5;  // D5 / GPIO6
static constexpr int PIN_LOP   = D8;  // D8 / GPIO7
static constexpr int PIN_LON   = D9;  // D9 / GPIO8

// ----------------------------------------------------------------------
// BLE UUIDs
// ----------------------------------------------------------------------
static constexpr char BLE_NAME[]  = "PinaBiosensor";
static constexpr char UUID_SVC[]  = "6b1d0001-5e8a-4c2f-9b3a-2c7f0e1a4d90";
static constexpr char UUID_JSON[] = "6b1d0002-5e8a-4c2f-9b3a-2c7f0e1a4d90";
static constexpr char UUID_CMD[]  = "6b1d0003-5e8a-4c2f-9b3a-2c7f0e1a4d90";
static constexpr char UUID_ECG[]  = "6b1d0004-5e8a-4c2f-9b3a-2c7f0e1a4d90";
static constexpr char UUID_PPG[]  = "6b1d0005-5e8a-4c2f-9b3a-2c7f0e1a4d90";
static constexpr char UUID_TEL[]  = "6b1d0006-5e8a-4c2f-9b3a-2c7f0e1a4d90";
static constexpr char UUID_EVT[]  = "6b1d0007-5e8a-4c2f-9b3a-2c7f0e1a4d90";

// ----------------------------------------------------------------------
// Acquisition defaults
// ----------------------------------------------------------------------
static constexpr uint16_t ECG_RATE_DEFAULT    = 250;
static constexpr uint16_t ECG_RATE_MAX        = 500;
static constexpr uint16_t PPG_RATE_DEFAULT    = 200;
static constexpr uint16_t GSR_RATE_DEFAULT    = 10;
static constexpr uint16_t THORAX_RATE_DEFAULT = 20;
static constexpr uint16_t ABDOMEN_RATE_DEFAULT= 20;
static constexpr uint16_t ADC_BUDGET_SPS      = 650;

static constexpr float GSR_VREF_DEFAULT = 0.500f;
static constexpr float GSR_FIXED_R      = 100000.0f;
static constexpr float GSR_SERIES_R     = 1000.0f; // PCB R11

static constexpr uint32_t TELEMETRY_PERIOD_MS = 100;  // 10 Hz
static constexpr uint32_t DIAG_PERIOD_MS      = 2000;
static constexpr uint32_t SLEEP_HOLD_MS       = 40;
static constexpr uint32_t I2C_TIMEOUT_MS       = 20;
static constexpr uint32_t ADS_CONV_TIMEOUT_US  = 4000;
static constexpr uint32_t PPG_POLL_MS           = 3;

// ----------------------------------------------------------------------
// Binary protocol
// ----------------------------------------------------------------------
// Header (12 bytes):
//   0 magic 0xA5
//   1 type (1=ECG, 2=PPG, 3=TELEMETRY, 4=EVENT)
//   2 version = 1
//   3 flags
//   4..5 sequence LE
//   6..9 first timestamp, ms from boot LE
//   10..11 nominal/estimated sample period, us LE
//   12 sample count
// Payload follows. CRC16-CCITT is last 2 bytes.
// ECG sample: int16 raw, LE.
// PPG sample: uint24 IR + uint24 RED, LE (18-bit source packed into 24 bits).
static constexpr uint8_t PROTOCOL_VERSION = 1;
static constexpr uint8_t PACKET_MAGIC     = 0xA5;
static constexpr uint16_t DEFAULT_ATT_MTU  = 23;

// ----------------------------------------------------------------------
// Types and state
// ----------------------------------------------------------------------
enum AdcChan : uint8_t { CH_ECG = 0, CH_GSR = 1, CH_THORAX = 2, CH_ABDOMEN = 3, CH_NONE = 255 };

enum RunState : uint8_t { STATE_STOPPED = 0, STATE_RUNNING = 1 };

struct ESample {
  int16_t raw;
  uint32_t tsUs; // microseconds since session start, wraps after ~71.6 min
};

struct PSample {
  uint32_t ir;
  uint32_t red;
  uint32_t tsUs; // microseconds since session start, wraps after ~71.6 min
};

struct SlowSample {
  uint32_t tsUs;
  float gsrUs;
  float thoraxV;
  float abdomenV;
  float tempC;
  float battV;
  uint16_t hr;
  uint16_t rrMs;
  uint8_t lo;
  uint8_t adsOk;
  uint8_t ppgOk;
  uint8_t tempOk;
};

struct CmdMsg {
  char text[128];
};

enum GainMode : uint8_t { GAINMODE_ONE = 0, GAINMODE_EIGHT = 1 };

struct AdcSlot {
  uint64_t nextDueUs;
  AdcChan lastChan;
  GainMode lastGain;
};

// ----------------------------------------------------------------------
// Globals
// ----------------------------------------------------------------------
MAX30105 ppg;
Preferences prefs;

BLEServer *bleServer = nullptr;
BLECharacteristic *chJson = nullptr;
BLECharacteristic *chCmd = nullptr;
BLECharacteristic *chEcg = nullptr;
BLECharacteristic *chPpg = nullptr;
BLECharacteristic *chTel = nullptr;
BLECharacteristic *chEvt = nullptr;
BLECharacteristic *chHr = nullptr;

SemaphoreHandle_t i2cMutex = nullptr;
SemaphoreHandle_t bleMutex = nullptr;
QueueHandle_t cmdQueue = nullptr;

TaskHandle_t adcTaskHandle = nullptr;
TaskHandle_t ppgTaskHandle = nullptr;
TaskHandle_t slowTaskHandle = nullptr;
TaskHandle_t commsTaskHandle = nullptr;
TaskHandle_t sleepTaskHandle = nullptr;

portMUX_TYPE ecgMux = portMUX_INITIALIZER_UNLOCKED;
portMUX_TYPE ppgMux = portMUX_INITIALIZER_UNLOCKED;
portMUX_TYPE telMux = portMUX_INITIALIZER_UNLOCKED;

volatile bool bleConnected = false;
volatile bool sleepRequested = false;
volatile bool deepSleeping = false;

RunState runState = STATE_RUNNING;

bool enEcg = true;
bool enGsr = true;
bool enThorax = true;
bool enAbdomen = true;
bool enPpg = true;
bool enTemp = true;
bool enBattery = true;

bool streamEcg = true;
bool streamPpg = true;
bool streamTelemetry = true;
bool streamJson = false;
bool txUsb = true;
bool txBle = true;
bool usbEcgStream = false;
bool usbPpgStream = false;
bool autoEcgBoost = true;

uint16_t ecgRateCfg = ECG_RATE_DEFAULT;
uint16_t ppgRateCfg = PPG_RATE_DEFAULT;
uint16_t gsrRateCfg = GSR_RATE_DEFAULT;
uint16_t thoraxRateCfg = THORAX_RATE_DEFAULT;
uint16_t abdomenRateCfg = ABDOMEN_RATE_DEFAULT;
float gsrVref = GSR_VREF_DEFAULT;

bool adsOk = false;
bool ppgOk = false;
bool tempOk = false;

float lastEcgV = 0.0f;
float lastGsrUs = 0.0f;
float lastThoraxV = 0.0f;
float lastAbdomenV = 0.0f;
float lastTempC = 0.0f;
float lastBattV = 0.0f;
uint8_t lastLo = 0;

uint16_t ppgHr = 0;
uint16_t ppgRrMs = 0;
uint32_t lastBeatTsMs = 0;
uint16_t hrHist[4] = {0,0,0,0};
uint8_t hrHistCount = 0;

uint32_t adcSamples[4] = {0,0,0,0};
uint32_t adcErrors[4] = {0,0,0,0};
uint32_t adcMuxChanges = 0;
uint32_t adcConversions = 0;
uint32_t ppgSamples = 0;
uint32_t ecgPackets = 0;
uint32_t ppgPackets = 0;
uint32_t telPackets = 0;
uint32_t eventPackets = 0;
uint32_t ecgDrops = 0;
uint32_t ppgDrops = 0;
uint32_t cmdDrops = 0;
uint32_t bleNotifyAttempts = 0;
uint32_t bleNotifyRejected = 0;

uint16_t ecgSeq = 0;
uint16_t ppgSeq = 0;
uint16_t telSeq = 0;
uint16_t evtSeq = 0;

uint32_t sessionStartMs = 0;
uint64_t sessionStartUs = 0;
uint32_t lastTelemetryMs = 0;
uint32_t lastDiagMs = 0;
uint32_t configDirtySinceMs = 0;
bool configDirty = false;

// ----------------------------------------------------------------------
// Ring buffers
// ----------------------------------------------------------------------
static constexpr size_t ECG_RING_CAP = 2048;
static constexpr size_t PPG_RING_CAP = 1024;
static constexpr size_t TEL_RING_CAP = 64;

ESample ecgRing[ECG_RING_CAP];
size_t ecgHead = 0, ecgTail = 0;
PSample ppgRing[PPG_RING_CAP];
size_t ppgHead = 0, ppgTail = 0;
SlowSample telRing[TEL_RING_CAP];
size_t telHead = 0, telTail = 0;

// ----------------------------------------------------------------------
// Small helpers
// ----------------------------------------------------------------------
static uint32_t nowMs() {
  return (uint32_t)(esp_timer_get_time() / 1000ULL);
}

static uint32_t sessionUs32() {
  return (uint32_t)((uint64_t)esp_timer_get_time() - sessionStartUs);
}

static uint16_t clampU16(long v) {
  if (v < 0) return 0;
  if (v > 65535L) return 65535;
  return (uint16_t)v;
}

static uint32_t clampU32(long long v) {
  if (v < 0) return 0;
  if ((unsigned long long)v > 0xFFFFFFFFULL) return 0xFFFFFFFFUL;
  return (uint32_t)v;
}

static uint16_t crc16ccitt(const uint8_t *data, size_t len) {
  uint16_t crc = 0xFFFF;
  for (size_t i = 0; i < len; ++i) {
    crc ^= (uint16_t)data[i] << 8;
    for (uint8_t b = 0; b < 8; ++b) {
      crc = (crc & 0x8000U) ? (uint16_t)((crc << 1) ^ 0x1021U) : (uint16_t)(crc << 1);
    }
  }
  return crc;
}

static void putU16(uint8_t *p, uint16_t v) {
  p[0] = (uint8_t)(v & 0xFFU);
  p[1] = (uint8_t)(v >> 8);
}

static void putU32(uint8_t *p, uint32_t v) {
  p[0] = (uint8_t)(v & 0xFFU);
  p[1] = (uint8_t)((v >> 8) & 0xFFU);
  p[2] = (uint8_t)((v >> 16) & 0xFFU);
  p[3] = (uint8_t)((v >> 24) & 0xFFU);
}

static void putU24(uint8_t *p, uint32_t v) {
  p[0] = (uint8_t)(v & 0xFFU);
  p[1] = (uint8_t)((v >> 8) & 0xFFU);
  p[2] = (uint8_t)((v >> 16) & 0xFFU);
}

static float adsRawToVolts(int16_t raw, GainMode gain) {
  float fsr = 4.096f;
  switch (gain) {
    case GAINMODE_ONE:   fsr = 4.096f; break;
    case GAINMODE_EIGHT: fsr = 0.512f; break;
    default:             fsr = 4.096f; break;
  }
  return ((float)raw * fsr) / 32768.0f;
}

static float calcGsrUs(float vMid) {
  if (!isfinite(vMid)) return 0.0f;
  if (vMid <= 0.002f) return 0.0f;
  if (vMid >= (gsrVref - 0.002f)) return 0.0f;
  float total = GSR_FIXED_R * vMid / (gsrVref - vMid);
  float skin = total - GSR_SERIES_R;
  if (!isfinite(skin) || skin <= 100.0f) return 0.0f;
  return 1000000.0f / skin;
}

static uint16_t adcTotalBudget() {
  uint32_t total = 0;
  if (enEcg) {
    uint16_t ecgEff = ecgRateCfg;
    if (autoEcgBoost) {
      uint32_t slow = 0;
      if (enGsr) slow += gsrRateCfg;
      if (enThorax) slow += thoraxRateCfg;
      if (enAbdomen) slow += abdomenRateCfg;
      uint32_t headroom = (slow < ADC_BUDGET_SPS) ? (ADC_BUDGET_SPS - slow) : ECG_RATE_DEFAULT;
      if (headroom > ECG_RATE_MAX) headroom = ECG_RATE_MAX;
      if (headroom < ECG_RATE_DEFAULT) headroom = ECG_RATE_DEFAULT;
      ecgEff = (uint16_t)headroom;
    }
    total += ecgEff;
  }
  if (enGsr) total += gsrRateCfg;
  if (enThorax) total += thoraxRateCfg;
  if (enAbdomen) total += abdomenRateCfg;
  return (total > 65535U) ? 65535U : (uint16_t)total;
}

static uint16_t effectiveEcgRate() {
  if (!enEcg) return 0;
  if (!autoEcgBoost) return ecgRateCfg;
  uint32_t slow = 0;
  if (enGsr) slow += gsrRateCfg;
  if (enThorax) slow += thoraxRateCfg;
  if (enAbdomen) slow += abdomenRateCfg;
  uint32_t headroom = (slow < ADC_BUDGET_SPS) ? (ADC_BUDGET_SPS - slow) : ECG_RATE_DEFAULT;
  if (headroom < ECG_RATE_DEFAULT) headroom = ECG_RATE_DEFAULT;
  if (headroom > ECG_RATE_MAX) headroom = ECG_RATE_MAX;
  return (uint16_t)headroom;
}

static bool enabled(AdcChan c) {
  if (c == CH_ECG) return enEcg;
  if (c == CH_GSR) return enGsr;
  if (c == CH_THORAX) return enThorax;
  if (c == CH_ABDOMEN) return enAbdomen;
  return false;
}

static uint16_t targetRate(AdcChan c) {
  if (!enabled(c)) return 0;
  if (c == CH_ECG) return effectiveEcgRate();
  if (c == CH_GSR) return gsrRateCfg;
  if (c == CH_THORAX) return thoraxRateCfg;
  if (c == CH_ABDOMEN) return abdomenRateCfg;
  return 0;
}

static GainMode gainFor(AdcChan c) {
  return (c == CH_GSR) ? GAINMODE_EIGHT : GAINMODE_ONE;
}

// ----------------------------------------------------------------------
// Ring buffers
// ----------------------------------------------------------------------
static bool ecgPush(const ESample &s) {
  bool overwritten = false;
  portENTER_CRITICAL(&ecgMux);
  size_t next = (ecgHead + 1) % ECG_RING_CAP;
  if (next == ecgTail) {
    ecgTail = (ecgTail + 1) % ECG_RING_CAP;
    ecgDrops++;
    overwritten = true;
  }
  ecgRing[ecgHead] = s;
  ecgHead = next;
  portEXIT_CRITICAL(&ecgMux);
  return !overwritten;
}

static bool ecgPop(ESample &s) {
  bool ok = false;
  portENTER_CRITICAL(&ecgMux);
  if (ecgTail != ecgHead) {
    s = ecgRing[ecgTail];
    ecgTail = (ecgTail + 1) % ECG_RING_CAP;
    ok = true;
  }
  portEXIT_CRITICAL(&ecgMux);
  return ok;
}

static size_t ecgCount() {
  size_t n;
  portENTER_CRITICAL(&ecgMux);
  n = (ecgHead >= ecgTail) ? (ecgHead - ecgTail) : (ECG_RING_CAP - ecgTail + ecgHead);
  portEXIT_CRITICAL(&ecgMux);
  return n;
}

static bool ppgPush(const PSample &s) {
  bool overwritten = false;
  portENTER_CRITICAL(&ppgMux);
  size_t next = (ppgHead + 1) % PPG_RING_CAP;
  if (next == ppgTail) {
    ppgTail = (ppgTail + 1) % PPG_RING_CAP;
    ppgDrops++;
    overwritten = true;
  }
  ppgRing[ppgHead] = s;
  ppgHead = next;
  portEXIT_CRITICAL(&ppgMux);
  return !overwritten;
}

static bool ppgPop(PSample &s) {
  bool ok = false;
  portENTER_CRITICAL(&ppgMux);
  if (ppgTail != ppgHead) {
    s = ppgRing[ppgTail];
    ppgTail = (ppgTail + 1) % PPG_RING_CAP;
    ok = true;
  }
  portEXIT_CRITICAL(&ppgMux);
  return ok;
}

static size_t ppgCount() {
  size_t n;
  portENTER_CRITICAL(&ppgMux);
  n = (ppgHead >= ppgTail) ? (ppgHead - ppgTail) : (PPG_RING_CAP - ppgTail + ppgHead);
  portEXIT_CRITICAL(&ppgMux);
  return n;
}

static bool telPush(const SlowSample &s) {
  bool overwritten = false;
  portENTER_CRITICAL(&telMux);
  size_t next = (telHead + 1) % TEL_RING_CAP;
  if (next == telTail) {
    telTail = (telTail + 1) % TEL_RING_CAP;
    overwritten = true;
  }
  telRing[telHead] = s;
  telHead = next;
  portEXIT_CRITICAL(&telMux);
  return !overwritten;
}

static bool telPop(SlowSample &s) {
  bool ok = false;
  portENTER_CRITICAL(&telMux);
  if (telTail != telHead) {
    s = telRing[telTail];
    telTail = (telTail + 1) % TEL_RING_CAP;
    ok = true;
  }
  portEXIT_CRITICAL(&telMux);
  return ok;
}

static size_t telCount() {
  size_t n;
  portENTER_CRITICAL(&telMux);
  n = (telHead >= telTail) ? (telHead - telTail) : (TEL_RING_CAP - telTail + telHead);
  portEXIT_CRITICAL(&telMux);
  return n;
}

static void clearBuffers() {
  portENTER_CRITICAL(&ecgMux);
  ecgHead = ecgTail = 0;
  portEXIT_CRITICAL(&ecgMux);
  portENTER_CRITICAL(&ppgMux);
  ppgHead = ppgTail = 0;
  portEXIT_CRITICAL(&ppgMux);
  portENTER_CRITICAL(&telMux);
  telHead = telTail = 0;
  portEXIT_CRITICAL(&telMux);
}

// ----------------------------------------------------------------------
// Low-level ADS1115 single-shot engine
// This avoids the repeated comparator-threshold writes performed by the
// generic Adafruit startADCReading() helper on every conversion. The PCB's
// ALERT pin is not wired to the XIAO, so we poll OS in the config register.
// ----------------------------------------------------------------------
static constexpr uint16_t ADS_REG_CONVERSION = 0x00;
static constexpr uint16_t ADS_REG_CONFIG     = 0x01;
static constexpr uint16_t ADS_OS_START       = 0x8000;
static constexpr uint16_t ADS_MUX_BASE       = 0x4000;
static constexpr uint16_t ADS_PGA_ONE        = 0x0200;
static constexpr uint16_t ADS_PGA_EIGHT      = 0x0400;
static constexpr uint16_t ADS_MODE_SINGLE    = 0x0100;
static constexpr uint16_t ADS_DR_860         = 0x00E0;
static constexpr uint16_t ADS_CQUE_DISABLE   = 0x0003;

static bool adsWriteConfig(uint16_t config) {
  if (!i2cMutex || !xSemaphoreTake(i2cMutex, pdMS_TO_TICKS(I2C_TIMEOUT_MS))) return false;
  Wire.beginTransmission(ADS_ADDR);
  Wire.write((uint8_t)ADS_REG_CONFIG);
  Wire.write((uint8_t)(config >> 8));
  Wire.write((uint8_t)(config & 0xFF));
  uint8_t err = Wire.endTransmission(true);
  xSemaphoreGive(i2cMutex);
  return err == 0;
}

static bool adsReadReg16(uint8_t reg, uint16_t &value) {
  if (!i2cMutex || !xSemaphoreTake(i2cMutex, pdMS_TO_TICKS(I2C_TIMEOUT_MS))) return false;
  Wire.beginTransmission(ADS_ADDR);
  Wire.write(reg);
  uint8_t err = Wire.endTransmission(false);
  if (err != 0) {
    xSemaphoreGive(i2cMutex);
    return false;
  }
  uint8_t got = Wire.requestFrom((int)ADS_ADDR, 2, true);
  if (got != 2) {
    xSemaphoreGive(i2cMutex);
    return false;
  }
  value = ((uint16_t)Wire.read() << 8) | Wire.read();
  xSemaphoreGive(i2cMutex);
  return true;
}

static uint16_t adsMuxBits(AdcChan c) {
  return (uint16_t)(ADS_MUX_BASE + ((uint16_t)c << 12));
}

static uint16_t adsGainBits(GainMode g) {
  return (g == GAINMODE_EIGHT) ? ADS_PGA_EIGHT : ADS_PGA_ONE;
}

static bool adsStartAndRead(AdcChan c, int16_t &raw, uint32_t &tsUs) {
  GainMode gain = gainFor(c);
  uint16_t cfg = ADS_OS_START | adsMuxBits(c) | adsGainBits(gain) |
                 ADS_MODE_SINGLE | ADS_DR_860 | ADS_CQUE_DISABLE;

  if (!adsWriteConfig(cfg)) return false;

  uint32_t startUs = (uint32_t)esp_timer_get_time();
  while ((uint32_t)(esp_timer_get_time() - startUs) < ADS_CONV_TIMEOUT_US) {
    uint16_t cval = 0;
    if (!adsReadReg16(ADS_REG_CONFIG, cval)) return false;
    if (cval & ADS_OS_START) break;
    vTaskDelay(1);
  }

  uint16_t raw16 = 0;
  if (!adsReadReg16(ADS_REG_CONVERSION, raw16)) return false;
  raw = (int16_t)raw16;
  tsUs = sessionUs32();
  return true;
}

static bool probeI2C(uint8_t addr) {
  if (!i2cMutex || !xSemaphoreTake(i2cMutex, pdMS_TO_TICKS(I2C_TIMEOUT_MS))) return false;
  Wire.beginTransmission(addr);
  uint8_t err = Wire.endTransmission(true);
  xSemaphoreGive(i2cMutex);
  return err == 0;
}

// ----------------------------------------------------------------------
// ADS scheduler
// ----------------------------------------------------------------------
static AdcSlot adcSlots[4];
static volatile bool adcScheduleDirty = true;

static void rebuildAdcSchedule() {
  uint64_t t = (uint64_t)esp_timer_get_time();
  for (uint8_t i = 0; i < 4; ++i) {
    AdcChan c = (AdcChan)i;
    adcSlots[i].nextDueUs = enabled(c) ? t : UINT64_MAX;
    adcSlots[i].lastChan = CH_NONE;
    adcSlots[i].lastGain = GAINMODE_ONE;
  }
  adcScheduleDirty = false;
}

static AdcChan pickNextAdcChannel(uint64_t nowUs) {
  if (adcScheduleDirty) rebuildAdcSchedule();
  AdcChan best = CH_NONE;
  uint64_t bestDue = UINT64_MAX;
  for (uint8_t i = 0; i < 4; ++i) {
    AdcChan c = (AdcChan)i;
    if (!enabled(c)) continue;
    uint16_t rate = targetRate(c);
    if (rate == 0) continue;
    if (adcSlots[i].nextDueUs < bestDue) {
      bestDue = adcSlots[i].nextDueUs;
      best = c;
    }
  }
  if (best == CH_NONE) return CH_NONE;
  if (bestDue > nowUs) {
    uint64_t waitUs = bestDue - nowUs;
    if (waitUs > 1500) {
      vTaskDelay(pdMS_TO_TICKS((uint32_t)(waitUs / 1000ULL)));
    } else {
      delayMicroseconds((uint32_t)waitUs);
    }
  }
  return best;
}

static void processAdcSample(AdcChan c, int16_t raw, uint32_t tsUs) {
  const uint8_t idx = (uint8_t)c;
  const GainMode gain = gainFor(c);
  const float v = adsRawToVolts(raw, gain);
  adcSamples[idx]++;

  if (c == CH_ECG) {
    lastEcgV = v;
    ecgPush({raw, tsUs});
  } else if (c == CH_GSR) {
    lastGsrUs = calcGsrUs(v);
  } else if (c == CH_THORAX) {
    lastThoraxV = v;
  } else if (c == CH_ABDOMEN) {
    lastAbdomenV = v;
  }
}

static void adcTask(void *arg) {
  (void)arg;
  rebuildAdcSchedule();

  for (;;) {
    if (runState != STATE_RUNNING || !adsOk || deepSleeping) {
      vTaskDelay(pdMS_TO_TICKS(10));
      continue;
    }

    uint64_t now = (uint64_t)esp_timer_get_time();
    AdcChan c = pickNextAdcChannel(now);
    if (c == CH_NONE) {
      vTaskDelay(pdMS_TO_TICKS(5));
      continue;
    }

    const uint8_t idx = (uint8_t)c;
    const GainMode g = gainFor(c);
    if (adcSlots[idx].lastChan != c || adcSlots[idx].lastGain != g) {
      if (adcSlots[idx].lastChan != CH_NONE) adcMuxChanges++;
      adcSlots[idx].lastChan = c;
      adcSlots[idx].lastGain = g;
    }

    int16_t raw = 0;
    uint32_t ts = 0;
    if (adsStartAndRead(c, raw, ts)) {
      adcConversions++;
      processAdcSample(c, raw, ts);
    } else {
      adcErrors[idx]++;
    }

    const uint16_t rate = targetRate(c);
    if (rate == 0) {
      adcSlots[idx].nextDueUs = UINT64_MAX;
      continue;
    }
    const uint64_t periodUs = 1000000ULL / (uint64_t)rate;
    if (adcSlots[idx].nextDueUs == UINT64_MAX) adcSlots[idx].nextDueUs = now;
    adcSlots[idx].nextDueUs += periodUs;

    const uint64_t n2 = (uint64_t)esp_timer_get_time();
    if (adcSlots[idx].nextDueUs + 4ULL * periodUs < n2) {
      adcSlots[idx].nextDueUs = n2 + periodUs;
    }
  }
}
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
void loop() {
  // All runtime work is in FreeRTOS tasks.
  vTaskDelay(pdMS_TO_TICKS(1000));
}

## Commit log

2026-09-25 Initial PinaBio v1.0
    inaBio v1.0 is a personal biofeedback board, not a medical device and not for diagnosis. It reads skin conductance (GSR), optical pulse (MAX30102, HRV on the phone), approximate skin temperature (MAX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
    [BOM.csv, PinaBio_v1.1_bom_jlc.csv, PinaBio_v1_bom_jlc.csv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]
2026-09-28 Fix v1.3 PPG state and restore verified v1.0 fabrication archive
    [PinaBiosensor_Firmware_v1_3.ino]
